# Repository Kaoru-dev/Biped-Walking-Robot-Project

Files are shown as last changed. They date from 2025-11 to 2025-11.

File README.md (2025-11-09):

# Biped-Walking-Robot-Project

This repository documents the design of a 6-DOF biped race-walking robot, originally developed for the China Engineering Robot and International Open Competition. This project showcases the complete engineering workflow, from mechanical structure to hardware design and the software control architecture.

Note: This repository is focused on open-sourcing the hardware. 

## Core Function Demonstration
This robot was designed to complete a complex race course, requiring stable walking and full-body tumbling. The three core movements are:

This robot was designed to complete a complex race course, requiring stable walking and full-body tumbling. The three core movement modes are:

| Short-Stride Gait | Long-Stride Gait | Tumbling |
| :---: | :---: | :---: |
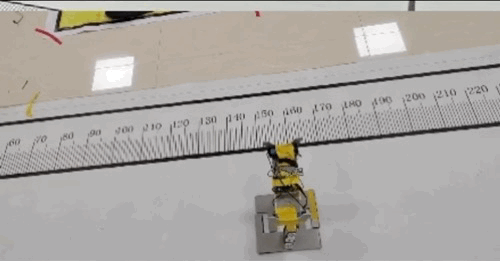
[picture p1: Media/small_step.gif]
Robot small step demo
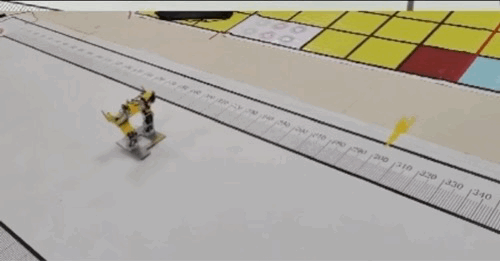
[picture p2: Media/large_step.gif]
Robot large step demo
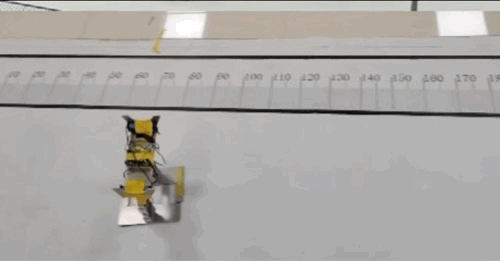
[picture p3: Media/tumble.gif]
Robot tumble demo
|  |  |  |

## Mechanical Structure
The robot is a 6-DOF bipedal platform, with each leg having 3 degrees of freedom (hip, knee, and ankle). This configuration allows for complex movements like walking, turning, and tumbling.

* **Design:** The entire structure was modeled in SolidWorks.
* **Materials:** To balance weight and strength, the main structural components (footplates, shoulder plates) are made of **6061 Aluminum Alloy**, while the U-shaped connectors are made from 2mm hard aluminum.
  
<p align="center">
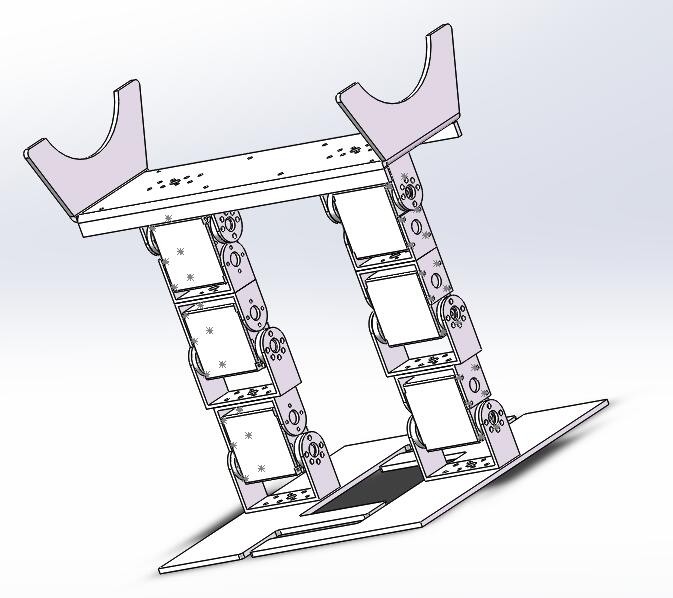
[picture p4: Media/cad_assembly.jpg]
CAD Assembly Drawing
  
</p>

## Hardware Design

The hardware system I designed is centered around the **ATmega16** microcontroller and is built on a custom-designed PCB.

A key part of the design is the power system. To maximize torque, the six **LDX-218 servos** are powered directly from a **7.4V** (2x 18650 Li-ion) rail. A separate **5V** logic rail for the ATmega16 and other components is created using an **AMS1117-5.0** voltage regulator. This separation ensures the high current draw from the servos does not cause a brownout or reset the microcontroller.

| Component | Specification |
| :--- | :--- |
| **Control MCU** | 1x ATmega16 (AVR) |
| **Actuators** | 6x LDX-218 Servos |
| **Power Supply** | 2x 18650 Li-ion Batteries (7.4V) |
| **Voltage Regulator**| AMS1117-5.0 | 

## Software Design

The firmware is written in **C** for the **ATmega16** microcontroller. It is designed for high-precision, real-time control of all six joints.

* **Software PWM Control:** The core of the firmware uses **Timer1** (Overflow and Compare Match interrupts) to generate 6 independent, high-resolution PWM signals entirely in software. This allows precise angle control for all servos without relying on limited hardware PWM channels.
* **Motion Interpolation:** A smooth motion loop moves each servo from its `current_value` to the `target` value at a calculated `pspeed`. This ensures all joint movements are synchronized and smooth, rather than sudden.
* **Gait Execution:** In `RUN` mode, the firmware executes pre-defined action groups (gait data) stored in the `workdata` array. It parses this array for target angles, speeds, and delays to perform complex sequences like walking or tumbling.
* **Debug & Communication:** A `DEBUG` mode is included, which uses the **UART** serial interface (9600 baud) to receive commands from a PC-side application, allowing for live testing and calibration of servo positions.

The image below shows the PC host application used for debugging the robot.
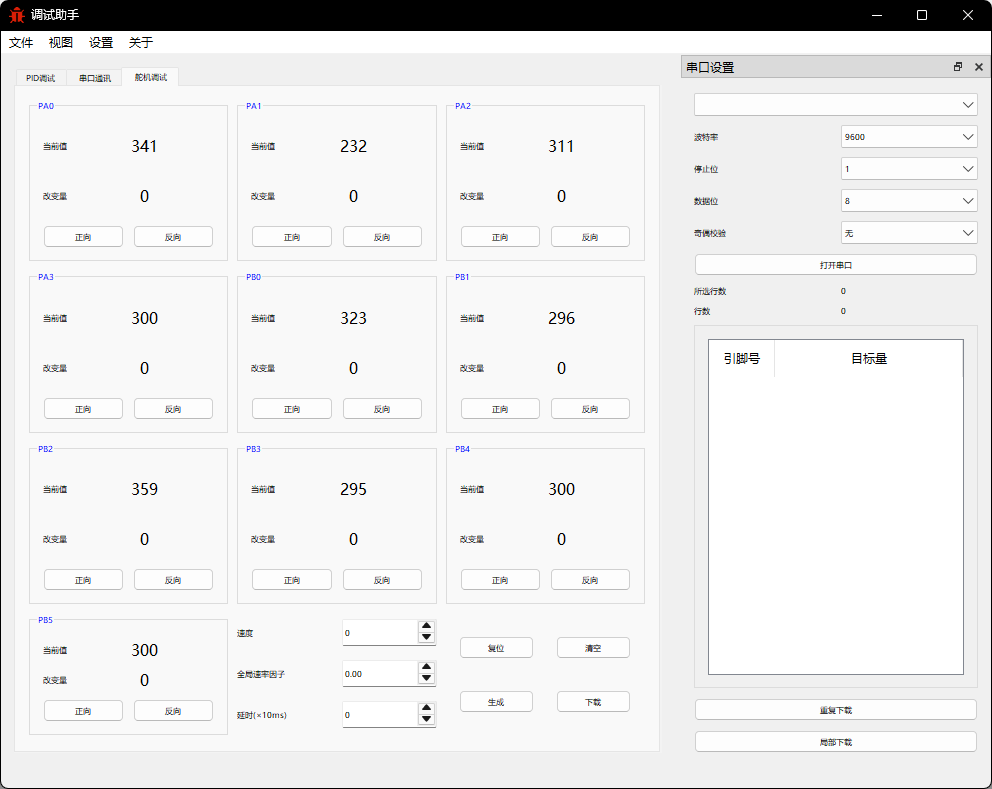
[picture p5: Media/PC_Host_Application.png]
PC Host Application for Debugging


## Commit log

2025-11-09 circuit documents
    [Servo control board.PcbDoc, Servo control board.SchDoc]
2025-11-09 Add robot CAD assembly drawing
2025-11-09 Add CAD assembly drawing to README
2025-11-09 Include CAD assembly drawing in README
    Added CAD assembly drawing to README
2025-11-09 Change CAD assembly image to HTML format
    Updated image formatting for CAD assembly drawing.
2025-11-09 Replace PNG assembly drawing with JPG version
2025-11-09 Update project description in README.md
    Removed 'CAD modeling' from project description for clarity.
